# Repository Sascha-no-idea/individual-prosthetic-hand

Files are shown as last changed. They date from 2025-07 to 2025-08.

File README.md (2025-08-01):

# Open-Source Pediatric Hand Prosthesis (v4)

This repository documents the ongoing development of a lightweight, low-cost, and child-friendly 3D-printed hand prosthesis for a 9-year-old. The project started as part of a mechanical engineering course at TU Berlin and is actively being developed further.

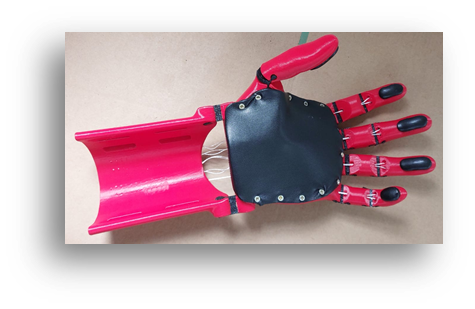
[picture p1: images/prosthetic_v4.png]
Prosthetic Hand
\
*Figure: Final design of the prosthetic hand (v4)*

---

## Project Background

The prosthesis is designed to be operated via wrist flexion and provide basic gripping functionality to support everyday activities. It is inspired by existing open-source prosthetic designs, especially from the [e-NABLE community](https://enablingthefuture.org/), and is built using accessible materials and FDM 3D printing.

---

## Project Goals

- **Individually adaptable** to user anatomy
- **Inexpensive** to produce (low-cost and standard materials)
- **Scalable and reproducible** for broader accessibility
- **Withstanding daily use**: robust, washable, skin-friendly
- **Comfortable and ergonomic**
- **Easily modifiable** and "grows" with the child
- **Printable on common FDM printers** with standard materials (PETG, TPU)

---

## Current Design Version: v4

The fourth generation (`v4`) of our design includes:

- ✅ Redesigned grip surfaces for better everyday usability
- ✅ Strong but flexible joints using TPU
- ✅ Custom string tension system (mechanical clamp)
- ✅ Modular components (easy replacement, adjustability)
- ✅ Printed using **PETG** and **TPU**, with **Dyneema®** cords

See [`/v4_final_design`](./v4_final_design/) for all STL files, assembly notes, and material details.

---

## Optimization Focus Areas

We evaluated and improved key components through iterative testing:

- `material-selection/` — optimal filament + cord materials (PETG, Dyneema)
- `finger-design/` — grip geometry & modularity
- `joint-mechanism/` — strength vs. complexity
- `band-routing/` — minimizing friction and response delay
- `tensor-system/` — new back-tensioner design
- `grip-surface/` — various high-friction materials tested
- `fit-scaling/` — adaptive sizing for different users

Detailed discussions and test results can be found under [`/optimization`](./optimization/).

---

## Repo Structure

| Folder | Description |
|---|---|
| `docs/` | Documentation and project presentation (PDF) |
| `v4_final_design/` | All current STL files and build instructions |
| `optimisation/` | Subfolders for each tested feature/improvement |
| `resources/` | Source models from e-NABLE, literature references |

---

## Credits & Acknowledgements

We gratefully acknowledge the open-source foundation by:

- [e-NABLE Kinetic Hand](https://www.thingiverse.com/thing:4618922)
- [Flexy-Hand by Gyrobot](https://www.thingiverse.com/thing:380665)

This project was developed by:
- Kristina Leberer  
- Sascha Thiede  
- Jonte Fricke  

as part of the course **"3D-Druck in der Mechanik"** at TU Berlin, supervised by **Prof. Dr. C. Völlmecke**, **Yating Ou (M.Sc.)**, and **Narges Panjalipoursangari (M.Sc.)**.

---

## Status

🟢 **v4 complete and functional**  
 - Further enhancements (grip elements, heat shrink tube, print-in-place design) in development.
- We're not in yet in contact with e-NABLE, but we plan to share our findings with them directly.

---

## Contact

For questions, feedback or collaboration proposals, feel free to open an issue or contact us directly.

---

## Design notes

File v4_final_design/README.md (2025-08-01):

# v4 Final Design – Quick Start Guide

This folder contains everything needed to replicate our current working version (v4) of the pediatric wrist-actuated prosthetic hand.

The design is based on the **Kinetic Hand by Mat Bowell**, maintained by the [e-NABLE community](https://enablingthefuture.org/). We've made minor but significant improvements to simplify usability, comfort, and assembly — particularly around the **tensioner system** and **material selection**.

---

## Required Base Files

The full set of STL files for the Kinetic Hand can be downloaded from:

🔗 [Kinetic Hand on Thingiverse](https://www.thingiverse.com/thing:4618922)

These files include all standard parts such as the palm, fingers, hinges, gauntlet, and wrist components.

We recommend downloading the latest official ZIP from Thingiverse and **replacing only the following parts with ours**.

---

## Custom Parts (included in this folder)

Located under `stl/`:

| File | Description |
|---|---|
| `tensioner_v1.stl` | Our redesigned mechanical friction-based tensioner, replacing the default flexible tensioner. Enables one-handed cable adjustment with no glue or knots. |

---

## Materials Used

| Component | Material | Note |
|---|---|---|
| Main structure | PETG | Durable and easy to print |
| Joints & pads  | TPU | Flexible (Shore A ~95) |
| Tendon cords | Dyneema® (UHMwPE) | Extremely strong, low friction |

Full material rationale in [`../optimization/`](../optimization/02_material-selection/)

> *NOTE: PETG Print Settings*  
> - Nozzle: **240–250 °C**  
> - Bed: **75–85 °C**  
> - Layer height: **0.2 mm**  
> - Walls: **3+**  
> - Infill: **25–40%** (depending on part)  
> - Cooling: **OFF or low** to prevent layer delamination  
> - Adhesion: Use brim and glue stick if needed

> *NOTE: TPU Print Settings*  
> - Nozzle: **220–230 °C**  
> - Bed: **50–60 °C**  
> - Layer height: **0.15–0.2 mm**  
> - Infill: **100% for joints**, **10–30% for grip parts**  
> - Print speed: **20–30 mm/s**  
> - Retraction: **Minimal or off**  
> - Direct drive extruder recommended

---

##  Bill of Materials (v4 Prototype)

| Part | Material | Weight | Est. Cost (PETG: 16–22 €/kg, TPU: 18–25 €/kg) |
|---|---|---|---|
| Palm | PETG | 90 g | 1.44 € – 1.98 € |
| Gauntlet | PETG | 66 g | 1.05 € – 1.45 € |
| Gauntlet Cover | PETG | 13 g | 0.20 € – 0.27 € |
| Palm Cover | TPU | 15 g | 0.27 € – 0.38 € |
| Finger Plate | PETG | 52 g | 0.83 € – 1.14 € |
| Hinge Plate | TPU | 17 g | 0.31 € – 0.43 € |
| Grip Plate | TPU | 7 g | 0.13 € – 0.18 € |
| **TOTAL (Printed)**| – | **260 g** | **4.23 € – 5.38 €** |

> *Dyneema cord (0.4 mm): ~0.12 €/m used (~1.00 € total)*  
> *Fasteners: ~1.00–2.00 € depending on source*

**Total material cost: under 10 €**

## Tensioning System

Replace the default Kinetic Hand tensioners with our friction-clamp version. Instructions:

1. Route tendon cord through the channel
2. Loop cord around central screw hole
3. Tighten screw to secure cord in place
4. To adjust tension: slightly loosen and reposition

See details in [`../optimisation/`](../optimization/04_tensor-system/)

---

## Optional Add-Ons

- [`../optimisation/05_grip-surface/`](../optimisation/05_grip-surface/) – Test results and methods for grip materials  
- [`../optimisation/06_fit-scaling/`](../optimisation/06_fit-scaling/) – Notes on fit strategy and scaling method

---

## Licensing Notice

This version is a derivative work of:

- **Kinetic Hand by Mat Bowell**  
  [Thingiverse Link](https://www.thingiverse.com/thing:4618922)  
  Licensed under [CC BY-NC-SA 4.0](https://creativecommons.org/licenses/by-nc-sa/4.0/)

Our modifications and additions are released under the same license.  
See [`LICENSE`](../LICENSE) in the main repository root.

---

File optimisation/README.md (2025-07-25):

# Optimisation
This directory contains the optimisation process for the individual prosthetic hand project. We put a lot of effort into improving the design, materials, and functionality of the prosthesis and split the optimisation process into several subfolders, each focusing on a specific aspect of the prosthesis.

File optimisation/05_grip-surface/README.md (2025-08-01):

# Grip Surface Optimisation

This section documents our experiments with grip surface solutions to enhance the functionality of the prosthetic hand. Grip performance is critical for tasks like holding bottles, pens, or toys — especially for a child user.

While the Flexy-Hand used **smooth contact areas**, the default model for the Kinetic Hand has recommends two-component silicone or flexible filament inserts, these solutions come with significant drawbacks. We explored several alternatives — including a **custom hot glue in-place injection moulding** process developed during the project.

---

## Official Recommendations

The Kinetic Hand assembly guide suggests two main grip-enhancing approaches:

### 🔸 Silicone Inserts (Two-Part Silicone)

- **Method**: 3D print moulds and cast custom inserts
- **Material**: Skin-safe silicone, Shore A 25–45
- **Estimated Cost**: ~27 € for 500 g (no smaller sets available)
- **Pros**: High grip, skin-safe, durable
- **Cons**: Expensive, high effort, wasteful for small production

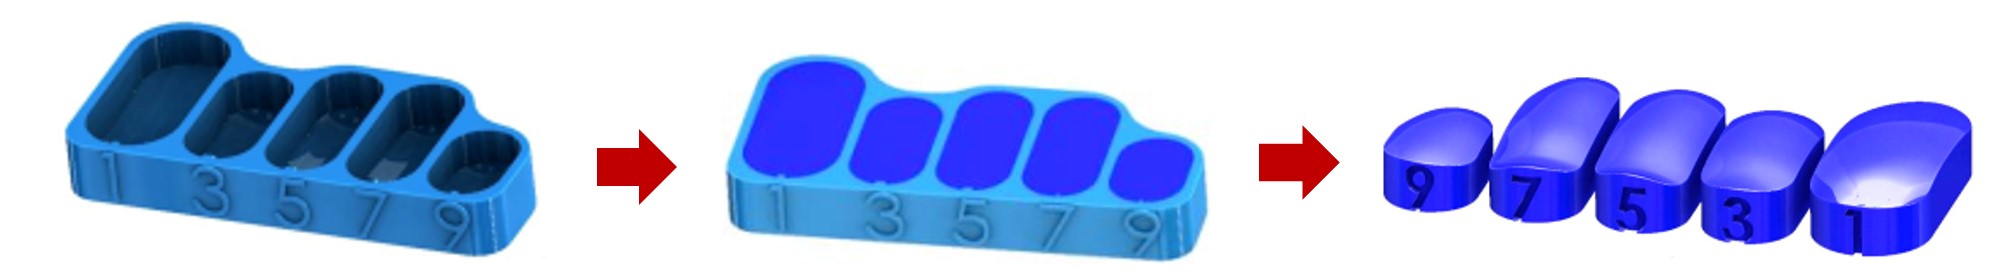
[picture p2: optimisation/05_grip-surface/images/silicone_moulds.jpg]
Silicone Insert Mould

*Figure: Printed silicone moulds for two part silicone (Image Source: Kinetic Hand Assembly Manual, Rev. 9/10/2020).*

---

### 🔸 Printed Grip with Ninjaflex

- **Method**: Print grip pads directly in ultra-flexible filament
- **Material**: Ninjaflex (Shore A ~85)
- **Estimated Cost**: ~30 € per 250 g spool
- **Pros**: Fully integrated into the model, good grip
- **Cons**: Very hard to print, not standard on most printers

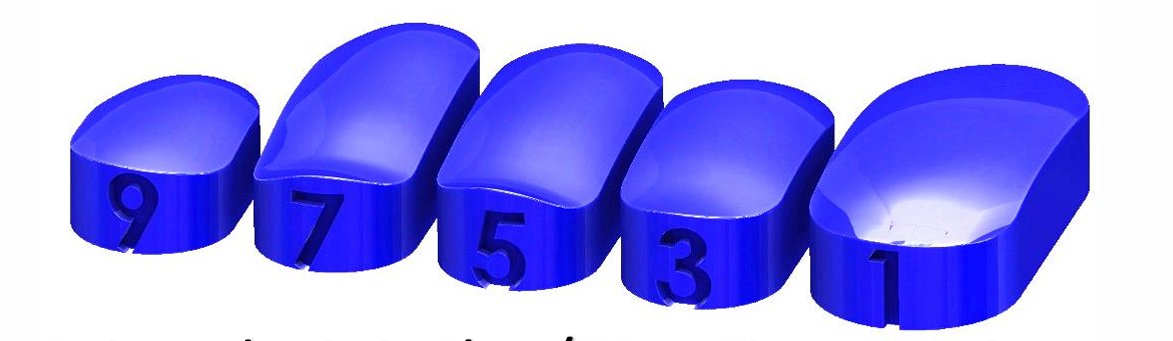
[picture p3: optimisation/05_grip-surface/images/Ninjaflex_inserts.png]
Ninjaflex Grip Example

*Figure: Example of Ninjaflex grip pads (Image Source: Kinetic Hand Assembly Manual, Rev. 9/10/2020).*

---

## Our Experiments & Alternatives

We tested several cost-effective and accessible alternatives, aiming for low manual effort, minimal cost, and wide availability.

---

### 🟠 1. Textured TPU Surface

- **Method**: Printed a grip surface with modeled texture using more affordable stanard TPU (Shore A ~90)
- **Pros**: Fully printable, no extra steps
- **Cons**: Too slippery; texture ineffective at this scale (on FDM printers)

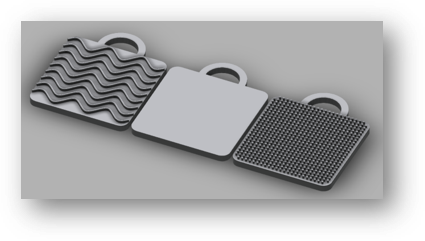
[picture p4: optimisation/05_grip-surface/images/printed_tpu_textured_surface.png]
Textured TPU Example


---

### 🟠 2. Full-Hand Latex Glove

- **Method**: Stretch a latex glove over the entire hand
- **Pros**: Good grip, instant coverage
- **Cons**: Not breathable → makes skin sweaty; less durable

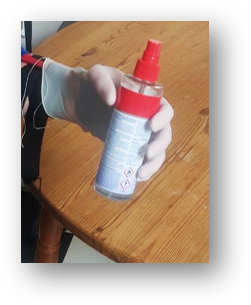
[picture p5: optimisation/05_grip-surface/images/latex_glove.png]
Latex Glove Example


---

### 🟢 3. Thick Latex Pads (Upcycled Material)

- **Method**: Cut grip pads from old latex leggings and glue them onto fingers and screw them onto the palm
- **Pros**: Very effective grip; comfortable; cost-efficient if sourced
- **Cons**: Manual cutting/gluing effort; sourcing may be inconsistent

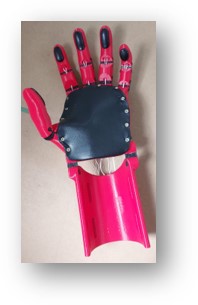
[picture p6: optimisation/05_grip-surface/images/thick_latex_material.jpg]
Latex Pad Example


💡 *This is the current solution used in our v4 prototype.*

---

### ✅ 4. Hot Glue In-Place Injection Moulding *(Experimental – v5 Candidate)*

- **Method**:  
  1. Design fingers with small recessed cavities  
  2. 3D-print a snap-on **injection mould** with a hole and fuzzy skin texture  
  3. Coat mould interior with **sugar water** as a release agent and let it dry  
  4. Snap mould onto finger  
  5. Inject **hot glue (130 °C)** into mould  
  6. Let it cool, remove mould, and rinse off sugar layer

- **Material**: Standard hot glue sticks (~Shore A 80)
- **Pros**:  
  - Extremely grippy  
  - Fast and low-cost  
  - No adhesives needed  
  - Permanent bond to the finger  
  - Moulds are reusable  
- **Cons**:  
  - Requires some heat control  
  - Not yet tested on full hand

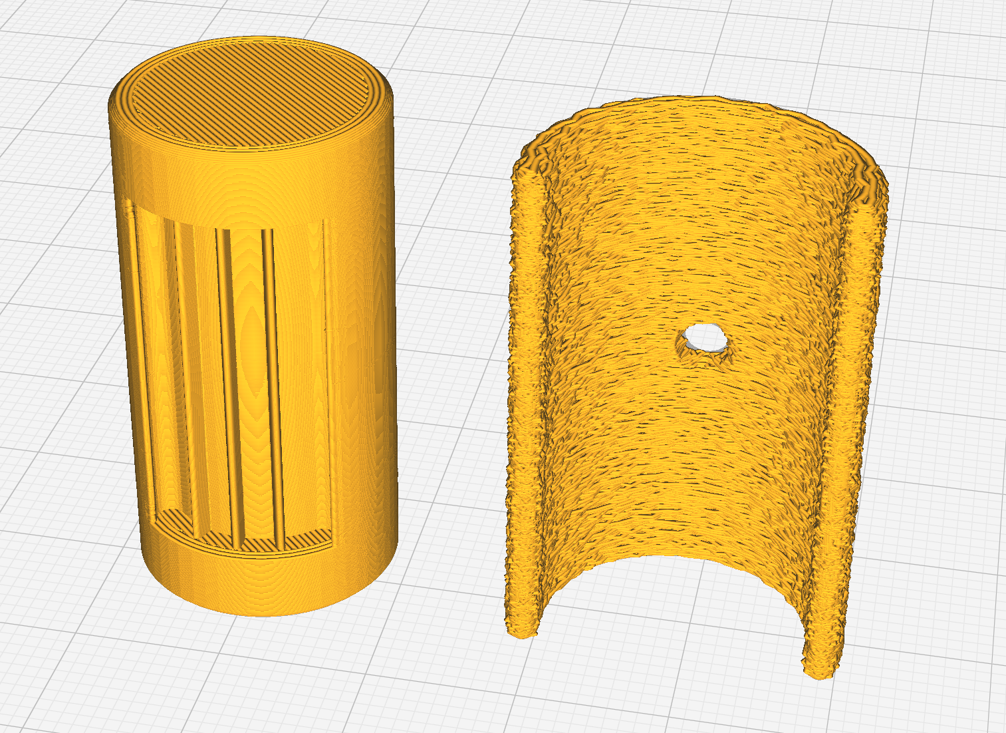
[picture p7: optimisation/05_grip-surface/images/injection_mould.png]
Test finger and snap-on mould
\
*Figure: Test finger with snap-on injection mould with fuzzy skin.*\
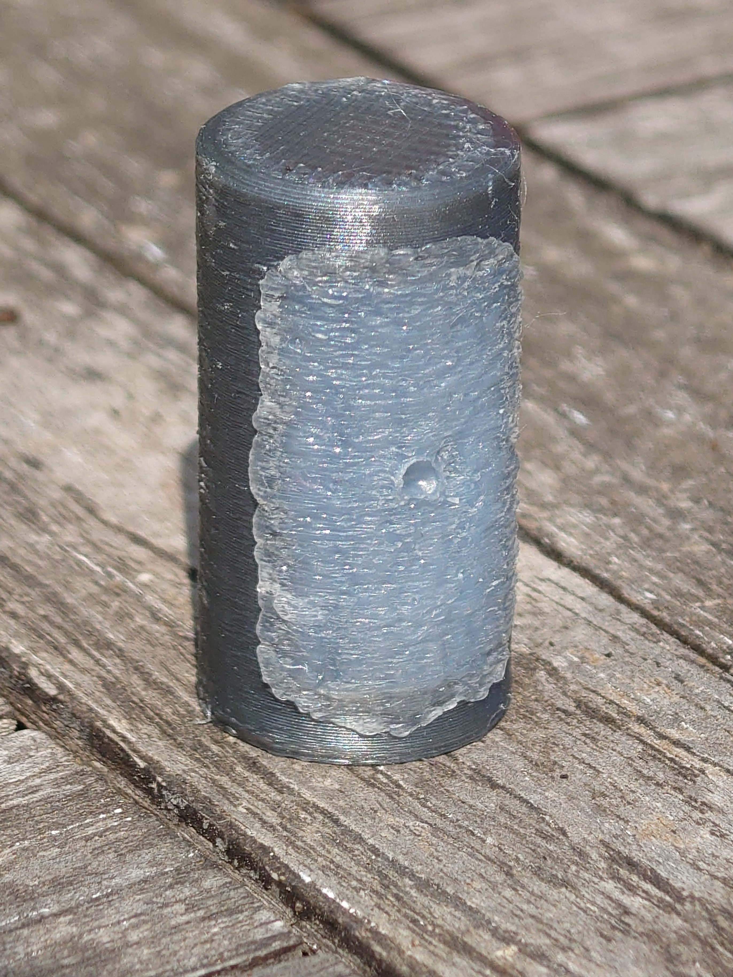
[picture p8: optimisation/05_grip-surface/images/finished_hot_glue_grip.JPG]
Finished hot glue grip
\
*Figure: Finished hot glue grip after injection and cooling.*

This technique will likely be included in our next version (v5).

---

## Summary of Tested Grip Solutions

| Method | Grip Quality | Cost  | Reusability | Required Tools | Status |
|---|---|---|---|---|---|
| Silicone inserts | ✅ High | 🔴 High | ✅ High | Casting tools, silicone| Not used |
| Ninjaflex print | ✅ High | 🔴 High | ✅ High | Soft-TPU-capable printer | Not used |
| Textured TPU | 🔴 Low | 🟢 Low | ✅ High | Basic FDM printer | Rejected |
| Latex glove | 🟢 Moderate | 🟢 Low | 🔴 Low | None | Rejected |
| Latex pads (upcycled) | ✅ High | 🟢 Low | 🟡 Medium | Scissors, glue | ✅ Used (v4)  |
| Hot glue injection mould  | ✅ High | 🟢 Low | ✅ High | Hot glue gun, mould | 🔜 v5 planned |

---

## Files & Resources

- `stl/grip_test_finger_with_cavity.stl` – Test finger with moulded grip cavity  
- `stl/hotglue_snap_mould.stl` – Snap-on grip mould 

---

## Learnings & Next Steps

- **Grip surface = critical** to daily usability, especially for small objects
- The **hot glue technique** is our most promising low-cost approach
- thick **latex material** already works well

---

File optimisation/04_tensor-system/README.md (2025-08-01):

# Tensor System

This section documents the design and motivation behind our custom **string tensioner system**. The tensioners are a crucial part of the prosthesis: they enable adjustment of the tendon cords that actuate the fingers via wrist movement.

---

## Standard Tensioner (Kinetic Hand Design)

The official Kinetic Hand assembly manual describes a multi-step process for installing and calibrating the tendon cords using **flexible tensioners**:

1. Screw the flexible tensioners into the gauntlet at one of several predefined positions.
2. Tie the tendon cord around the tensioner, initially with **temporary slip knots**.
3. Manually test the finger closure (adjusting for timing and symmetry).
4. Tie **permanent knots** (surgeon’s knot), apply **super glue**, and trim.
5. Optionally reposition the tensioners for final calibration.

**Drawbacks:**
- Requires **both hands** to tie knots and make adjustments.
- Tuning process is **time-consuming and difficult to repeat**.
- Knots and glue introduce **irreversible steps**.
- wear on screw holes with repeated adjustments.

*See the official assembly instructions (Step 12–21) for full procedure.*

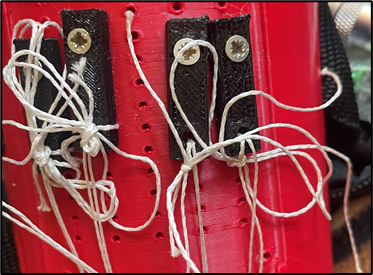
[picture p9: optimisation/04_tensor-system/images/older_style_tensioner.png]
Standard Tensioner


*Figure: Standard tensioner system from Kinetic Hand assembly manual, but with bow instead of surgeon’s knot during prototyping.*

---

## Our Custom Tensioner Design

To make the system more **user-friendly, reliable, and adjustable**, we designed a **two-part mechanical clamp** that holds the tendon in place by friction.

### Key Features:
- No knots or glue required
- Fully **adjustable with one hand**
- Uses only **a single M2 screw**
- Cords can be inserted, tightened, and re-tensioned **without tools**
- Reversible and reusable (decreases wear on screw holes)

### How It Works:

The custom tensioner consists of:
- A **base part** with a guide channel
- A **cap part** that clamps the tendon in place
- One **M2 screw** that connects both parts and compresses the cord

The cord is routed around the screw shaft and sandwiched between the two halves. As the screw is tightened, friction secures the cord firmly in position. To adjust, the screw is loosened slightly, the cord is pulled or released, and the screw is re-tightened.

<div style="display: flex;">
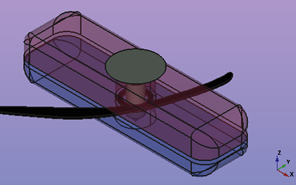
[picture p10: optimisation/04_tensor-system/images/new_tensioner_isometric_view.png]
New Tensioner CAD
  
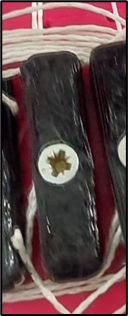
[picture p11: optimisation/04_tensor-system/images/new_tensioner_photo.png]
New Tensioner Assembly
  
</div>

*Figure 1: Isometric view of the new custom tensioner design.*\
*Figure 2: Image of the assembled new custom tensioner design.*

---

## Assembly Instructions

1. Insert the tendon cord into the guide path in the **base part**.
2. Loop the cord around the central screw hole.
3. Place the **cap part** on top.
4. Insert and tighten the **M2 screw** gently until resistance is felt.
5. Test the finger actuation.
6. Adjust by loosening and repositioning the cord as needed.

---

## Advantages at a Glance

| Feature | Standard System | Custom Tensioner |
|---|---|---|
| Tool-free adjustment | ❌ No | ✅ Yes |
| Requires knot tying | ✅ Yes | ❌ No |
| Requires glue | ✅ Yes | ❌ No |
| One-handed operation | ❌ No | ✅ Yes |
| Reusability | ❌ Limited | ✅ High |

---

## Files & Resources

- [`tensioner_custom_v1.stl`](../../v4_final_design/stl/Tensor_new.stl)

---

## Future Improvements

- Incorporate quick-release or snap-fit features for even faster cord swaps
- or increase longevity of screw holes, consider using a **threaded insert** instead of direct threads in the plastic

---

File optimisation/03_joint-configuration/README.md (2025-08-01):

# Joint Configuration

This section documents our evaluation of joint types used in the prosthetic fingers and palm. Finger joint design is critical to achieving a balance between stability, flexibility, durability, and ease of assembly.

We compared three joint types:

- **Flexible printed hinges (default TPU design)**  
- **Flexible joints with shrink tubing**  
- **Standard mechanical (pinned) joints**

---

## Overview of Joint Types

Joint Types Comparison
*Figure: Extract from project presentation slide (July 2025)*

---

## Why We Didn't Use Shrink Tubing (Yet)

Although the shrink-tube joint is promising — especially due to the clean look and quick assembly — we encountered **several material challenges**:

- Most common shrink tubing (polyolefin) is too **stiff** in larger diameters
- Wall thickness becomes problematic for our small-scale parts
- We ordered alternative materials: **braided PET tubing** and **thin silicone tubing**, but delivery was pending at the time of the current version (`v4`)
- Further material testing is planned — this joint type may still become a viable option for future versions

**Update (2025-07-31): Our Shrinking Tube order arrived**\
We tested:
- **Braided PET tubing**: Works in general, but sto stiff, not enough grip and not waterproof
- **PVC grip tubing (for fishing rod handles)**: Works exceptionally well, nice and thin, flexible, much better grip than polyelofin tubing, but PVC might contain harmful chemicals.
- **Silicone tubing (non-shrink, food grade)**: Works well, fit is a bit loose, because it does not shrink, we were not able to source larger diameters than ID 12 mm, OD 14 mm yet without thicker walls.

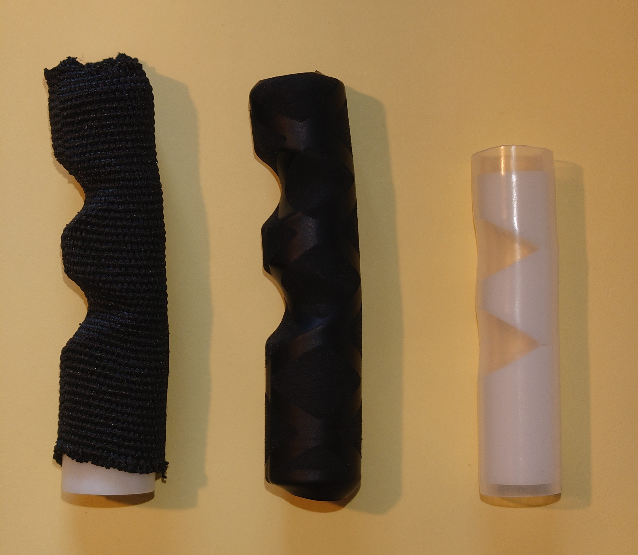
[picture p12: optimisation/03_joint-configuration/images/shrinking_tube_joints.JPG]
Shrink Tube Joint

*Figure: Print-in-place shrink tube joint test finger with braided PET tubing (left), PVC grip tubing (middle), and silicone tubing (right).*

Our current tests of this new joint type are very promising. Especially the PVC grip tubing works very well and provides reliable re-opening of the finger, but we are still concerned about the chemicals in PVC. The silicone tubing is a good alternative, although a bit stiff, and we need to find a source for larger diameters with thin walls. Furthermore, we need to test the long-term wear resistance, as non of these tubings are designed for repeated bending. Once these tests are complete, we can work on a print-in-place finger design that uses the shrink tube joint.

Shrink Tube Joint Bending Test
*Figure: Bending test of PVC grip tubing joint. The joint opens reliably, but we need to test long-term wear resistance.*

---

## Current Decision

For our current build (v4), we are using the **default flexible TPU joints** provided in the Kinetic Hand design. We optimized the **print settings** for these joints (infill, wall count, material choice) to ensure:

- Smooth opening motion after gripping
- Adequate flexibility for kid’s strength
- Durability over extended use

---

## Print Settings for TPU Joints

| Parameter | Value / Recommendation |
|---|---|
| Layer height | 0.2 |
| Wall/perimeter | 3 |
| Infill | 30 % |
| Print speed | 30 mm/s |
| Material used | TPU (Shore A 90) |

Please note that the actual print settings vary and depend on your specific TPU brand and printer configuration. The goal is to tune the strength of the joints so that the hand will reopen completely with no unnecessary increase in required closing force.

---

## Next Steps

We plan to revisit the shrink tube approach, given that our new material has arrived. Our goal is to evaluate:

- Long-term wear resistance
- Assembly effort
- Performance under repetitive motion

Furthermore, we will run more tests with **PCTG** as a potential joint material, which would enable us to print the entire hand in one piece, eliminating the need for joints altogether.

---

## References

- [Kinetic Hand on Thingiverse](https://www.thingiverse.com/thing:4618922) — original joint design
- Internal presentation slide (July 2025): *Comparison of joint types*

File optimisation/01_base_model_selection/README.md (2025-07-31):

# Base Model Selection

In this section we explain our selection process of an existing prosthetic as our base model for further development. In our initial research we found several open-source designs that could be used as a starting point. With our criteria in mind — especially the preference for flexible joints over mechanical pivot joints for simplicity and printability — we narrowed it down to two well-known models:

- [**Flexy-Hand 2** by Gyrobot](https://www.thingiverse.com/thing:380665)  
- [**Kinetic Hand** by Mat Bowell](https://www.thingiverse.com/thing:4618922)

Both are distributed and maintained by the [e-NABLE community](https://enablingthefuture.org/) and come with open-source licenses, making them suitable for educational and humanitarian use.

---

## Evaluation Criteria

We compared the models based on the following criteria:

- Simplicity of assembly  
- Modularity and adjustability  
- Suitability for children (size, safety, usability)  
- Maintenance and repairability  
- Printability on standard FDM printers  
- Availability of documentation and community support

---

## Comparison Table

| Feature | Flexy-Hand 2 by Gyrobot | Kinetic Hand by Mat Bowell |
|---|---|---|
| **Joint type** | Flexible (printed hinges) | Flexible (printed hinges) |
| **Finger grip surface** | Smooth (no texture) | Includes optional silicone inserts |
| **Seilzüge (tendon routing)**  | Open, exposed routing | Covered routing with palm cover |
| **Assembly complexity** | Very low | Moderate (more parts, hinges are hard to assemble) |
| **Fit customization** | Simple scaling | Advanced: Hand-o-matic | |
| **Documentation quality** | Limited | Very good (Thingiverse + PDF manuals) |
| **Visual appeal** | Basic | More anatomical & refined |
| **Tensor adjustability** | Linear screw tensors | Fixed TPU tensioners (limited adjustability) |
| **License & community support**| CC BY-NC-SA 4.0 | CC BY-NC-SA 4.0 |

---

## Decision & Rationale

We chose the **Kinetic Hand** by Mat Bowell as the foundation for our development due to the following advantages:

- Better grip design with modular surfaces
- enclosed tendon routing
- Visually more appealing and ergonomic
- Excellent documentation and broader community adoption

While it has more parts and requires more effort during assembly, its **long-term modularity and flexibility** made it a better foundation for an individually optimized prosthesis.

---

## Credits

- **Flexy-Hand 2** by Steve Wood / Gyrobot  
  - [Thingiverse page](https://www.thingiverse.com/thing:380665)  
  - [Gyrobot website](https://www.gyrobot.co.uk)

- **Kinetic Hand** by Mat Bowell  
  - [Thingiverse page](https://www.thingiverse.com/thing:4618922)  
  - [Free 3D Hands website](https://free3dhands.org/)
- **e-NABLE Community**  
  - [Enabling the Future](https://enablingthefuture.org/)

All designs used under open-source licenses. We are grateful to the creators and the e-NABLE community for their dedication to accessible prosthetics.

---

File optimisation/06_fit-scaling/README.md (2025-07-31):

# Fit & Scaling

This section documents our approach to adapting the prosthetic geometry to fit the user's hand, with a focus on **scaling strategy**, **comfort**, and **fit stability**. Ensuring a precise and ergonomic fit is essential for usability — especially for a growing child.

---

## Initial Idea: Non-Proportional Scaling

In our early experiments, we attempted **axis-specific (non-uniform) scaling** to better match the forearm's anatomical proportions. However, this led to multiple problems:

- 🚫 **Tendon channels collapsed** and became non-functional
- 🚫 **Joint geometry distorted**, leading to mechanical issues
- 🚫 **Finger proportions became unnatural and visually awkward**

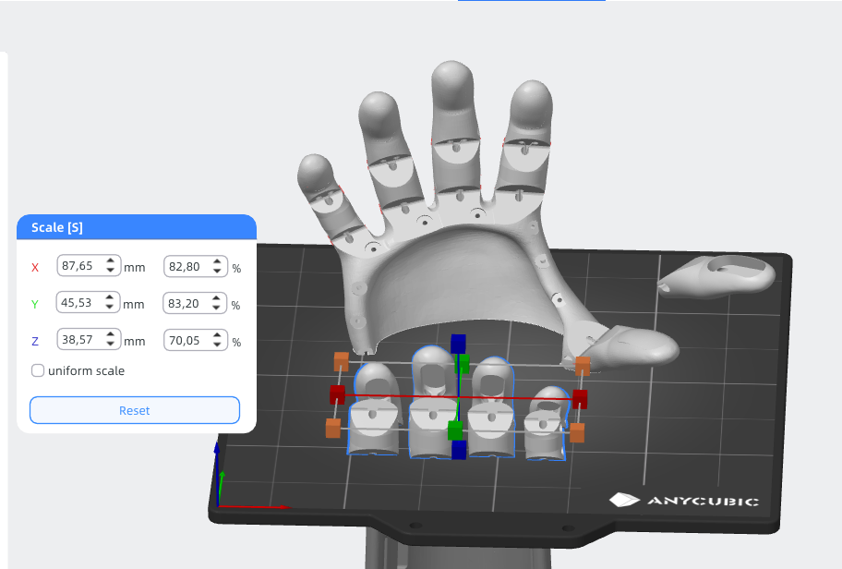
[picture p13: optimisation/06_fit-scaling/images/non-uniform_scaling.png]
Deformed Geometry Example

*Figure: Deformed geometry due to non-uniform scaling*

---

## Final Decision: Proportional Scaling

After encountering the issues with axis scaling, we returned to a simpler and more robust solution: **uniform (proportional) scaling** of the entire model.

- Required **no modifications** to the geometry
- Maintained **functional integrity** of the joints and tendon paths
- Produced a result that **fit our 9-year-old user** well

💡 *We did not need to rely on the sizing tables provided in the official documentation, because sizing was easy in our specfic case.*

---

## Fit Insert: Not Required in Our Case

The Kinetic Hand documentation describes optional **TPU fit inserts** to stabilize the wrist position and prevent the forearm from slipping inside the palm socket.

> *"The Insert is designed to be a soft cushion inside the Kinetic Hand. It stops the partial hand from sliding forward and keeps the wrist at the hinge position. It is shaped as a precise fit into the cavity of the Palm."*  
— *Kinetic Hand Assembly Manual, Step 26*

### Why We Didn't Use It

- Our proportional scaling resulted in a **snug, stable fit** for the user
- No noticeable sliding or discomfort was observed
- The wrist hinge aligned well with the user's joint without additional padding

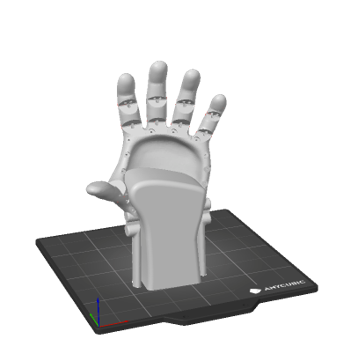
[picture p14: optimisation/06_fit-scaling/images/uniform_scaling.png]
Uniform Scaling Result


---

## Alternative Insert Options (Hypothetical)

If an insert had been required, we considered two affordable and low-tech alternatives:

### 1. Kitchen Silicone + Starch Putty (Untested)

- **Method**: Mix **hardware store silicone** with **cornstarch** to form a moldable, skin-safe padding that hardens over time
- **Pros**: Inexpensive, conformal, moldable by hand
- **Cons**: Requires drying time, emits acetic acid while curing

### 2. Foamed TPU (e.g. LW-TPU, Untested)

- **Method**: Print the insert using lightweight or foaming TPU to reduce weight and improve cushioning
- **Pros**: Lightweight, springy, printable
- **Cons**: Expensive, hard to source, needs tuned settings

> *Note: Neither approach was implemented in v4, but both remain valid ideas for future versions or other users with different anatomical requirements.*

---

## Summary

| Approach | Tested? | Result |
|---|---|---|
| Non-proportional scaling | ✅ Yes  | ❌ Rejected due to geometry and function issues |
| Proportional scaling | ✅ Yes  | ✅ Used in v4, provided excellent fit |
| TPU insert (standard) | ❌ No | Not needed |
| Silicone putty insert | ❌ No | Viable fallback (hypothetical) |
| Foamed TPU insert | ❌ No | Experimental idea for future |

---

## References

- *Kinetic Hand Assembly Manual*, e-NABLE (Step 26)  
- Internal presentation slides – Fit Scaling,  July 2025 
- Informal guides for DIY silicone putty (silicone + starch)

---

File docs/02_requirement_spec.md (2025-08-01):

# Requirement Specification – Pediatric Wrist-Actuated Hand Prosthesis

## 1. Project Purpose

The goal of this project is to develop a 3D-printable, wrist-actuated hand prosthesis for a 9-year-old user. The device should be low-cost, ergonomic, and enable the user to grasp everyday objects independently.

## 2. Functional Requirements

| ID | Requirement | Description |
|---|---|---|
| FR01 | Wrist-actuated finger motion | The prosthesis must enable grip via wrist flexion. |
| FR02 | Passive return to open state | Fingers must return to the default open state when wrist is relaxed. |
| FR03 | Object grasping | Must securely grasp objects such as a cup, pencil, or toy. |
| FR04 | Replaceable string system | Cables/strings should be replaceable and easy to calibrate. |

## 3. Non-Functional Requirements

| ID | Requirement | Description |
|---|---|---|
| NFR01 | Comfortable fit | Should not cause pain or discomfort during wear. |
| NFR02 | Durable materials | Components must withstand regular use by a child. |
| NFR03 | Lightweight | The prosthesis should not exceed 200 grams. |
| NFR04 | Hygienic and skin-safe materials | Materials must be biocompatible and easy to clean. |
| NFR05 | Cost-effective | Total material cost should remain under €10. |
| NFR06 | Openly reproducible | Design should use standard FDM materials and printers. |
| NFR07 | Modular design | Should allow partial replacements and scaling. |

## 4. Design Constraints

- Printable using FDM printers with nozzle ≥ 0.4 mm.
- No support structures required (where avoidable).
- Designed for printing with widely available and easy-to-print materials, like PETG and TPU.
- Cord system must avoid elastic materials like nylon.
- Maximum build plate size: 220 × 220 mm.

## 5. Intended Use & Limitations

- Designed for passive prosthetic use (no active sensors yet).
- Grip force depends on wrist motion and cord stiffness.
- Not intended for heavy load-bearing use or high-impact sports.

## 6. Stakeholders

- **End user**: 9-year-old child with partial forearm.
- **Family**: supports daily use and maintenance.
- **University Team**: responsible for design, testing, and documentation.
- **Open-source Community**: potential contributors and replicators.

---

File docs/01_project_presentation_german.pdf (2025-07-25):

Fakultät für Verkehrs- und Maschinensysteme
Institut für Mechanik

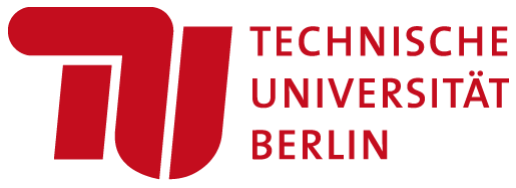
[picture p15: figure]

Fachgebiet Stabilität und Versagen funktionsoptimierter Strukturen Prof. Dr. C. Völlmecke

Gruppe C
Kristina S. Leberer
Sascha G. Thiede
Jonte C. Fricke

Projekt: 3D Druck in der Mechanik

# Die Handprothese

Seite 2 | Gruppe C | 3D-Druck in der Mechanik | Die Handprothese | 15. Juli 2025

# Agenda

- Motivation
- Projektziel und Problemkontext
- Projekte & Open-Source Community
- Vorgehen
- Meilensteine
- Iterative Herangehensweise
- Optimierungsziele
- Ergebnisse
- Optimierungen
- Kosten & Material
- Fazit
- Projektgestaltung und Umsetzung
- Bewertung der entstandenen Prothese
- Geplante Weiterentwicklungen und Unterstützung

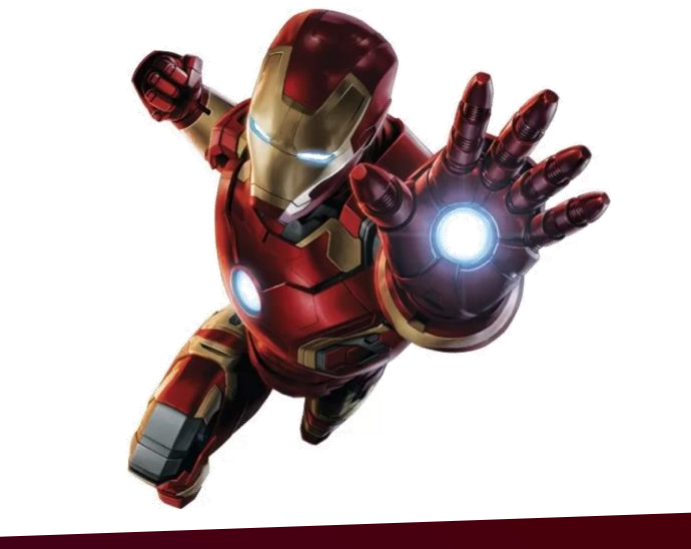
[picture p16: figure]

# Motivation

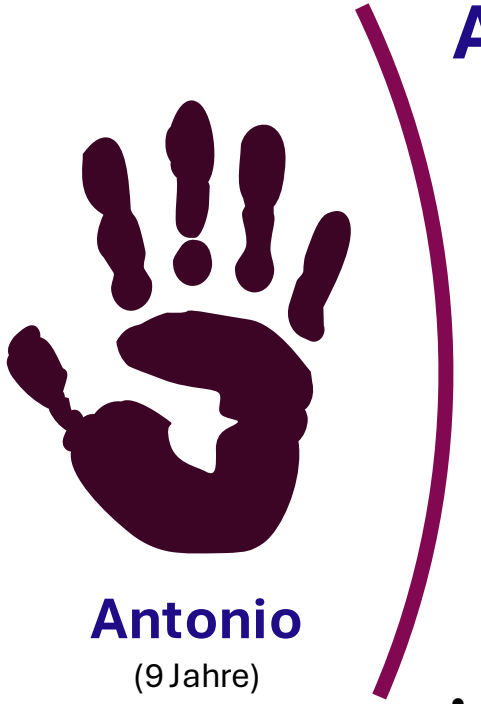
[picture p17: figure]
Antonio; (9 Jahre)

Seite 4 | Gruppe C | 3D-Druck in der Mechanik | Die Handprothese | 15. Juli 2025

# Projektziel

## Erstellung und individuellen Handprothese

# Anforderungen

### - individuell anpassbar

### - robust, funktional, zuverlässig

### - bequem & optisch ansprechend

### - kostengünstig herzustellen

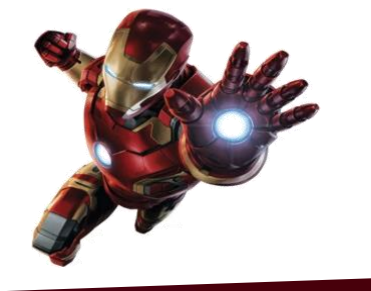
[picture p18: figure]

### - hygienisch & biokompatibel

### - einfach herzustellen

### - mitwachsend

Flexy-Hand by Gyrobot

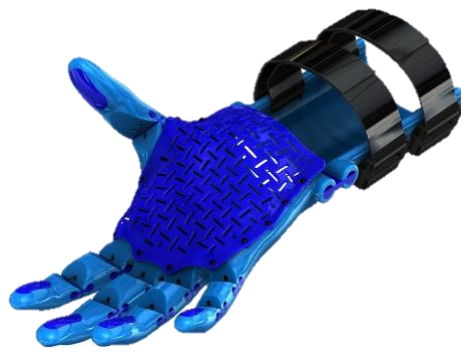
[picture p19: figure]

e-NABLE Kinetic Hand

https://www.thingiverse.com/thing:380665

https://www.thingiverse.com/thing:4618922

# e-NABLE (open-source Community)

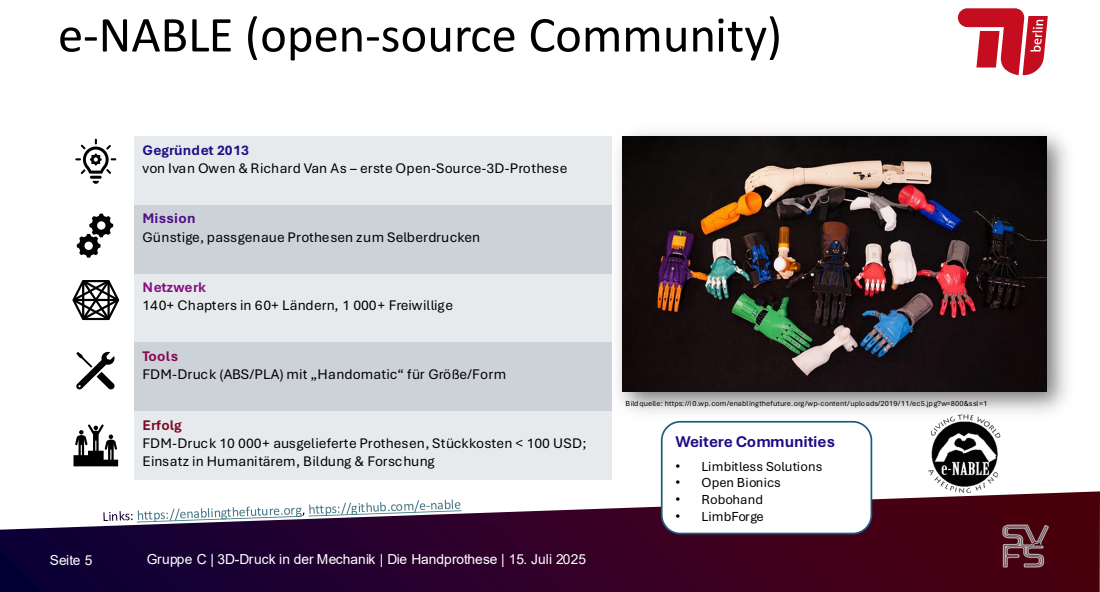
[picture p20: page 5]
Seite 5; Gruppe C | 3D-Druck in der Mechanik | Die Handprothese | 15. Juli 2025

Gegründet 2013
von Ivan Owen & Richard Van As – erste Open-Source-3D-Prothese

Mission
Günstige, passgenaue Prothesen zum Selberdrucken

Netzwerk
140+ Chapters in 60+ Ländern, 1 000+ Freiwillige

Tools
FDM-Druck (ABS/PLA) mit „Handomatic“ für Größe/Form

Bild quelle: https://i0.wp.com/enablingthefuture.org/wp-content/ uplo ads/2019/ 11/ec5.jp g?w=800&ssl=1
Weitere Communities
• Limbitless Solutions
• Open Bionics
• Robohand
• LimbForge

Erfolg
FDM-Druck 10 000+ ausgelieferte Prothesen, Stückkosten < 100 USD;
Einsatz in Humanitärem, Bildung & Forschung

# Vorgehen

Seite 7 | Gruppe C | 3D-Druck in der Mechanik | Die Handprothese | 15. Juli 2025

# Meilensteine

- Recherche
- Modellauswahl
- Maßaufnahme
- Problemanalyse
Recherche | Prototypenerstellung | Optimierung | Abschluss
| ▪ ausgewählte Modelle drucken ▪ Verarbeitungsverfahren testen ▪ Maßanpassung ▪ vertiefte Materialauswahl | ▪ Analyse der Haftreibung ▪ Griffstärke und -geometrie optimieren | ▪ Modell finalisieren ▪ Dokumentation ▪ Übergabe & Schulung

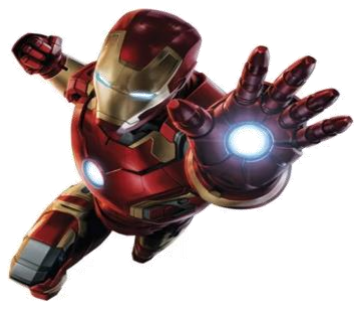
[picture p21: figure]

# Methodische Herangehensweise (iterativ)

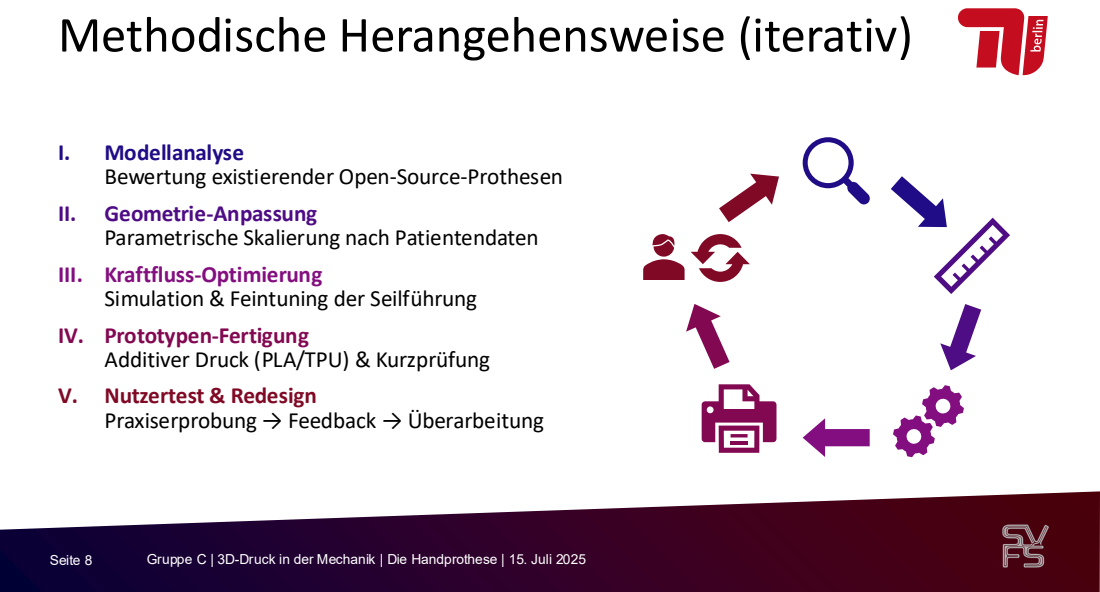
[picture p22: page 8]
Seite 8; Gruppe C | 3D-Druck in der Mechanik | Die Handprothese | 15. Juli 2025; Geometrie-Anpassung

I. Modellanalyse
Bewertung existierender Open-Source-Prothesen
Parametrische Skalierung nach Patientendaten
III. Kraftfluss-Optimierung
Simulation & Feintuning der Seilführung
IV. Prototypen-Fertigung
Additiver Druck (PLA/TPU) & Kurzprüfung
V. Nutzertest & Redesign
Praxiserprobung → Feedback → Überarbeitung

Seite 9 | Gruppe C | 3D-Druck in der Mechanik | Die Handprothese | 15. Juli 2025

# Optimierungsziele

Ergonomie Verbesserung von Tragekomfort und individueller Passform Funktionalität Sicheres Greifen alltäglicher Gegenstände mit möglichst wenig Kraftaufwand Materialwahl Leicht, robust, kostengünstig und für den Nachdruck geeignet Befestigungsmechanismus Stabiler Halt bei gleichzeitig einfacher Handhabung

### Anpassbarkeit & Modularität Möglichkeit zur schnellen Justierung und Erweiterung der Prothese

# Ergebnisse

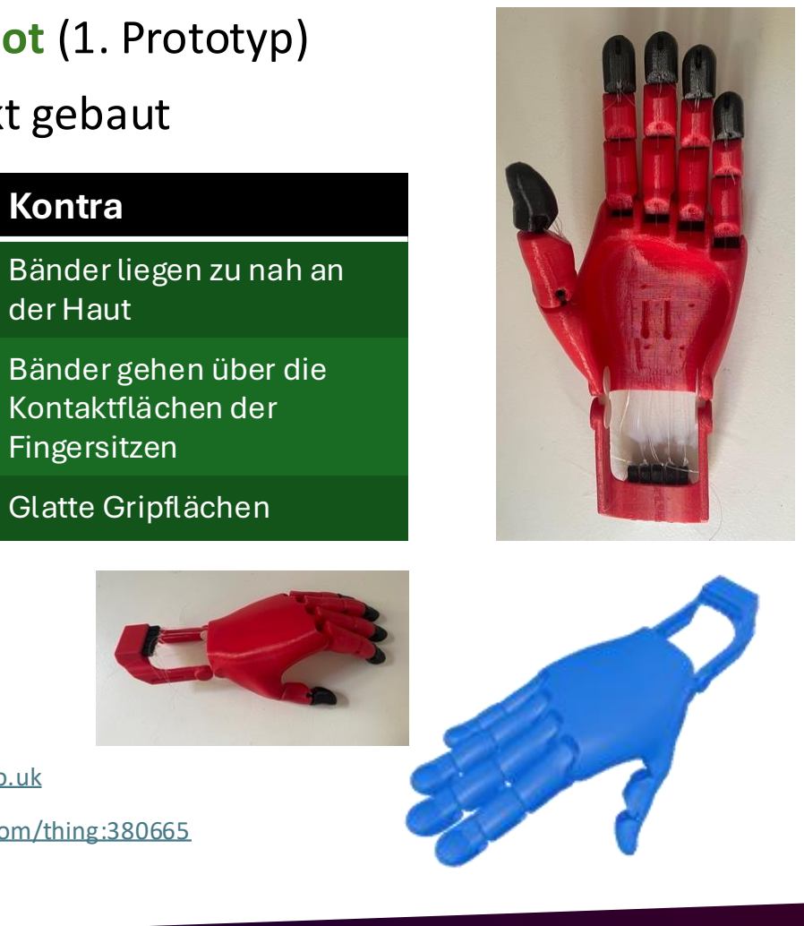
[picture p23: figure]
Bänder gehen über die Kontaktflächen der Fingersitzen; Glatte Gripflächen

Seite 11 | Gruppe C | 3D-Druck in der Mechanik | Die Handprothese | 15. Juli 2025

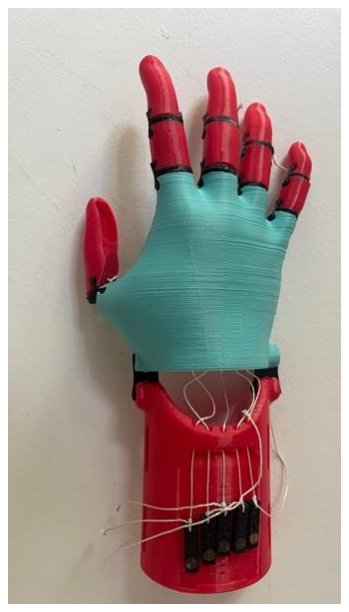
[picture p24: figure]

Model von e-NABLE (finales Model)
- im Projekt gebaut und optimiert

HOME: https://enablingthefuture.org

STL: https://www.thingiverse.com/thing:4618922

# Zwei Modelle

Model von Gyrobot (1. Prototyp)
- vor dem Projekt gebaut

HOME: https://www.gyrobot.co.uk

STL: https://www.thingiverse.com/thing:380665

Pro | Kontra
weniger Teile | Bänder liegen zu nah an
der Haut
Tensoren der Bänder
simple
Pro | Kontra
Form der
Handaussparung

mehr Teile

optisch ansprechender Tensoren nicht justierbar
bessere Anleitung | schwieriger beim Zusammenbauen der Gelenke

fortschrittlicher

Seite 12 | Gruppe C | 3D-Druck in der Mechanik | Die Handprothese | 15. Juli 2025

# Überblick: Optimierungsansätze

### - Materialwahl

Hand, Bänder

### - Herstellung

vereinfachte Verarbeitungsprozesse

### - Grip-Flächen

Material- und Oberflächenalternativen

### - Gelenke

TPU-Gelenke durch Schrumpfschlauch ersetzten

### - Tensoren

Bänderbefestigung mit einfacher Kalibrierungsmöglichkeit der Spannkraft

### - Bänder

Kraftverteilungsalternative

### - Innere Flächen

Bequemlichkeitsanpassung durch Handschuh

Bänder | Tensoren

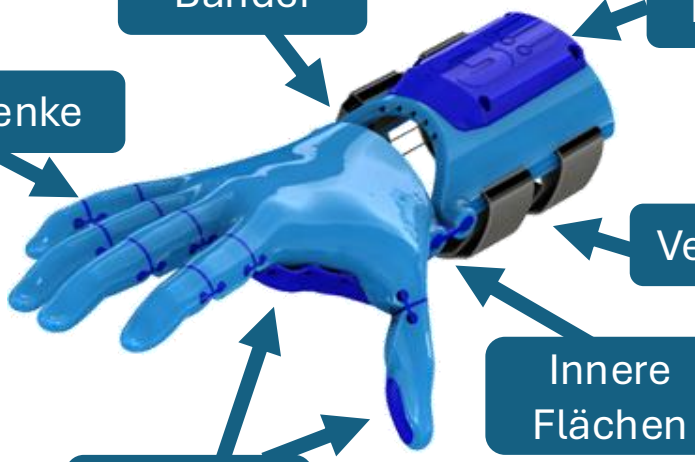
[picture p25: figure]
Innere Flächen

### Grip-Flächen

### Gelenke

### Verschluss

# Material Hand

PC-ABS | ABS | Nylon | PCTG | PLA/PLA

Seite 13; Gruppe C | 3D-Druck in der Mechanik | Die Handprothese | 15. Juli 2025; Robust?; Hygienisch?; Leicht druckbar?; Verfügbar?; Kostengünstig?; PETG; EIGNUNG

# Optimierung Seilzüge

## Nähzwirn

Seite 14; Gruppe C | 3D-Druck in der Mechanik | Die Handprothese | 15. Juli 2025; (Polyester, geflochten); Kevlar; (geflochten); Angelschnur Nylonschnur; (PE, geflochten); Dyneema; (UHMwPE); Verfügbarkeit; Preis EIGNUNG; Abriebfestigkeit; Dehnung

# Optimierung Gelenke

Seite 15; Gruppe C | 3D-Druck in der Mechanik | Die Handprothese | 15. Juli 2025; Standardgelenk; Flexibles Gelenk; Schrumpfschlauch-; Gelenk; Abnutzung Komplexität Stabilität; simpler Aufbau komplett druckbar langlebig Federwirkung weniger stabil

noch simpler
in einem Stück
druckbar
abgedichtet
verbesserter Grip
langlebig?

# Anatomische Passformoptimierung

## Skalierungsmöglichkeiten


Seite 16 | Gruppe C | 3D-Druck in der Mechanik | Die Handprothese | 15. Juli 2025

Verzehrte Skalierung:
- Problematisch bei der Banddurchführung
- Verzehrte Gelenke und Finger machen die Skalierung umständlicher und unproportional
Einfache Skalierung:
- Simple Umsetzung
- Druckbar ohne Stützstruktur


Seite 17 | Gruppe C | 3D-Druck in der Mechanik | Die Handprothese | 15. Juli 2025

# Befestigungsalternativen der Bänder


## Empfohlen von e-NABLE

### - Mit Kleber fixieren - TPU-Tensor -> dehnbar

## Neuer Tensor

### - Backentensor - nicht dehnbar - Fixierung mit Druckkraft - einfache Justierung:

1. Länge einstellen
2. Schraube festziehen
Solle einhändig möglich sein

# Gripelemente und Ideen


Seite 18 | Gruppe C | 3D-Druck in der Mechanik | Die Handprothese | 15. Juli 2025

## Empfohlen von e-NABLE

→ Silikoneinsätze in gedruckte Formen gießen

TPU mit modellierter Oberfläche | Latexhandschuh | Latexstoff | Spritzguss mit Heißkleber


Seite 19 | Gruppe C | 3D-Druck in der Mechanik | Die Handprothese | 15. Juli 2025

1.

# Bandführungsalternativen

## Model eines Fingers mit mehreren Befestigungspunkten

1. Ausgangspunkt (Standardmodell)
2. Standardmodell passt sich gut an Oberfläche an
- Halten von z.B. einem Türgriff
3. Finger öffnet sich wobei sich Spitze schließt



Seite 20 | Gruppe C | Gruppe C | 3D-Druck in der Mechanik | Die Handprothese | 15. Juli 2025 Druck in der Mechanik | Die Handprothese | 15/07/25
- Ausgangspunkt (Standardmodell)
- Standardmodell passt sich gut an Oberfläche an
- Halten von z.B. einem Türgriff
- Finger öffnet sich wobei sich Spitze schließt
- Idee: Individueller Seilzug pro Fingerglied mit Bowden-artiger Leitung der Züge
- Nachteil: Ist Starr, passt sich schlecht einer Oberfläche an

### Neue modellierte Finger

Projektionsmethode:

Ansicht von Oben

Ansicht von der Seite

Seite 21 | Gruppe C | Gruppe C | 3D-Druck in der Mechanik | Die Handprothese | 15. Juli 2025 Druck in der Mechanik | Die Handprothese | 15/07/25

### Finger

Plate | 52 g PETG

0,83 € -
1,14 €
Hinge Plate | 17g TPU | 0,31 € -0,43 €
Gauntlet | 66g PETG | 1,05 € -1,45 €
Grip Plate | 7g TPU | 0,13 € -0,18 €

### Gauntlet Cover

### 13g PETG

0,20 € -
0,27 €
Palm | 90g PETG | 1,44 € -1,98 €
Palm Cover | 15g TPU | 0,27 € -0,38 €

### PETG: 16 - 22 €/kg TPU: 18 - 25 €/kg

(Stand 2025-07)

### Gedruckte Teile: 4,23 - 5,38 €

## Kosten und Materialen


# Fazit

Seite 23 | Gruppe C | 3D-Druck in der Mechanik | Die Handprothese | 15. Juli 2025

# Fazit:

# Projektgestaltung und Umsetzung

- Erste Prothese basierend auf Open-Source-Daten
gebaut
- Anatomische Anpassungen nach ersten Treffen mit Antonio
- Kompletter Neuaufbau zur Verbesserung von Passform und Komfort
- Erste Krafttests und Alltagserprobung durch Antonio
- Nachjustierung der Feinmotorik basierend auf Nutzererfahrung
- Ergänzungen durch Antonios Mutter


Seite 24 | Gruppe C | 3D-Druck in der Mechanik | Die Handprothese | 15. Juli 2025

## Fazit:

# Bewertung der Prothese zum Projektabschluss

- Passform und Komfort deutlich verbessert
- Funktionalität im Alltag ausreichend für grundlegende Greifbewegung
- Nutzerfeedback positiv: intuitive Handhabung nach kurzer Eingewöhnung
- Materialwahl: PETG statt PLA (empfohlen) für höhere Belastbarkeit und
Temperaturbeständigkeit
- Reproduzierbarkeit: Design dient als Basis für weitere Exemplare (z.B. Ersatzprothese)
- Kosten unter < 10€ / Prothese
- Gewicht: 181g

Seite 25 | Gruppe C | 3D-Druck in der Mechanik | Die Handprothese | 15. Juli 2025

# Fazit:

# Weiterentwicklungen und zukünftige Unterstützung

- Neue Fingerkuppen aus hochreibungsfähigem Material zur Verbesserung
des Grips geplant
- Langfristige Unterstützung durch Sascha bei Wartung, Reparatur & Nachdruck
- Weitere Handschuhe in Arbeit – individuell angepasst durch die Mutter des Nutzers
- Ersatzprothese wird zeitnah auf Basis des optimierten Designs gefertigt
- Wissensaustausch: Optimierungserkenntnisse werden an die Open-Source-Community zurückgespielt
- Langfristige Perspektive: mögliche Integration von EMG-Sensorik zur aktiven Steuerung

Danke.

Ein großen Dank an Frau Prof. Dr. C. Völlmecke, die es uns ermöglicht hat, dieses Projekt mit kompetenter Beratung durchzuführen. Wir bedanken uns auch bei Yating Ou (M.Sc.) und Narges Panjalipoursangari (M.Sc.) für die stetige Unterstützung. Unser Dank geht auch an alle anderen Beteiligten, für ihr Ideenreichtum

und ihren Rat.

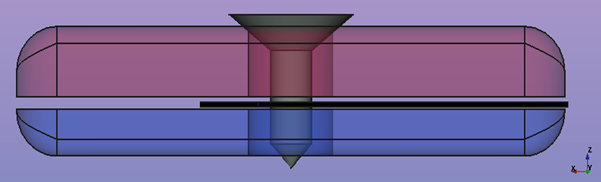
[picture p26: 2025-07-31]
optimisation/04_tensor-system/images/new_tensioner_side_view.png

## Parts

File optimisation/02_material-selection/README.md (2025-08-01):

# Material Selection

This section outlines the material selection process for the prosthetic hand, focusing on both the printed structural components and the cord system. Our goal was to ensure all materials used are suitable for a child-friendly prosthesis — considering **cost**, **availability**, **printability**, **durability**, and above all, **user safety**.

---

## Prosthesis Body

The base components of the prosthesis are produced via **FDM 3D printing**. Suitable materials must be:

- Non-toxic and skin-safe (biocompatible)
- Printable on standard consumer printers (no heated chamber)
- Mechanically durable and impact-resistant
- Resistant to cleaning agents and moderate heat
- Cost-effective and easily sourced (available in maker spaces)

We compared several common 3D printing materials:

Material Selection Chart  
*Figure: Extract from project presentation slide (July 2025)*

### Summary of Key Findings

- **PLA / PLA+**: Very easy to print and affordable, but insufficient temperature resistance. Risk of deformation in hot environments (e.g. car interiors).
- **PETG**: Excellent compromise — better temperature resistance and impact toughness than PLA. Widely available, inexpensive, and easy to print. Chosen as the **main body material**.
- **TPU**: Used selectively for **flexible joints**, due to high elasticity and fatigue resistance.
- **PCTG** *(emerging)*: Similar to PETG, but with improved impact strength and chemical resistance. Promising candidate for future iterations — could enable printed-in-place joints — but still slightly more expensive and less common.

---

## Cord System

The cord system is a critical mechanical component: it transmits motion from the wrist to the fingers. Material selection here directly affects **grip strength**, **responsiveness**, and **long-term reliability**.

Cord Material Selection Chart  
*Figure: Extract from project presentation slide (July 2025)*

### Summary of Key Findings

- **Nylon cords**: Too elastic — leads to energy loss and reduced grip strength.
- **Kevlar**: Strong, but prone to abrasion damage when routed through plastic guides.
- **Braided fishing line (PE)**: Commonly used in e-NABLE designs. Affordable and widely available, but variable in quality.
- **Dyneema® (UHMwPE)**: Exceptional strength-to-weight ratio, low friction, and almost no stretch (~3%). Extremely abrasion-resistant and ideal for compact tendon paths.  
  → Chosen as our **preferred material** (used: 0.4 mm diameter).

If Dyneema® is not available, we recommend using a **braided polyethylene fishing line** with a diameter of **0.3–0.5 mm** as a fallback.

---

## Summary of Material Choices

| Component | Material | Reason |
|---|---|---|
| Main body | PETG | Strong, heat-resistant, widely available |
| Joints | TPU | High elasticity, durable under repeated bending |
| Tendon cords | Dyneema® | Minimal stretch, high durability, low friction |

---

## References

- Internal presentation slide (July 2025): *Material Comparison*
- [e-NABLE community](https://enablingthefuture.org/) – Open-source prosthetic models  
- [Dyneema® product data](https://www.dsm.com/dyneema) – DSM Engineering Materials  
- Mat Bowell, [Kinetic Hand STL](https://www.thingiverse.com/thing:4618922)  
- Steve Wood, [Flexy-Hand STL](https://www.thingiverse.com/thing:380665)

---

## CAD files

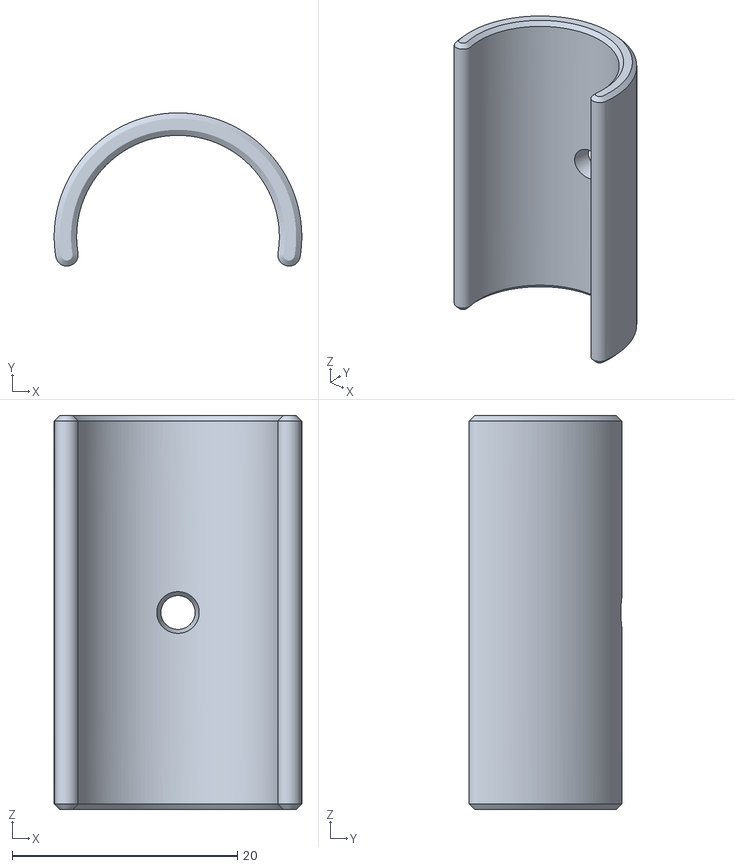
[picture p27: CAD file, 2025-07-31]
optimisation/05_grip-surface/stl/hotglue_snap_mould.stl
22.0 x 13.6 x 35.0

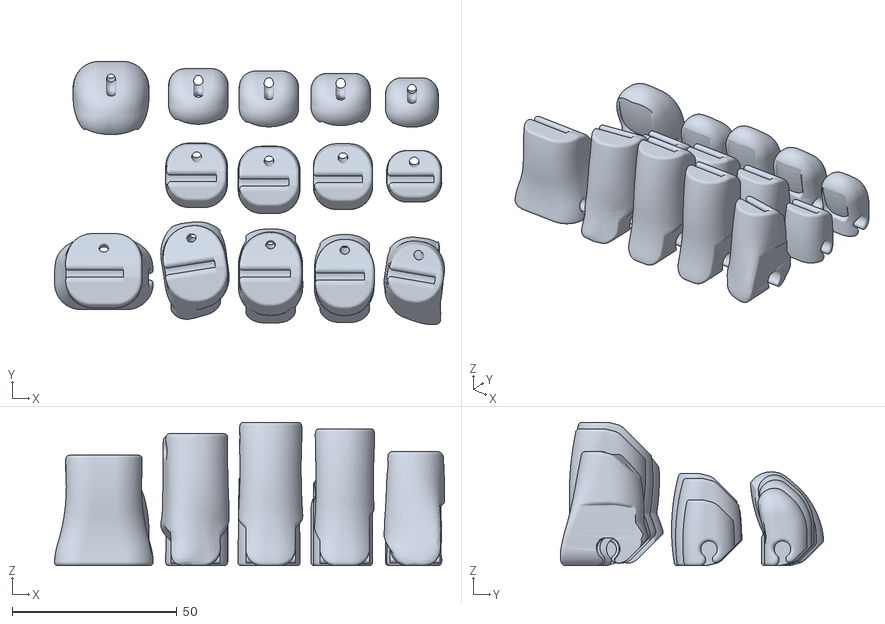
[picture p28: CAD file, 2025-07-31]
resources/original_models/flexy_hand/files/LH_Finger_Plate.stl
118.3 x 79.9 x 43.5

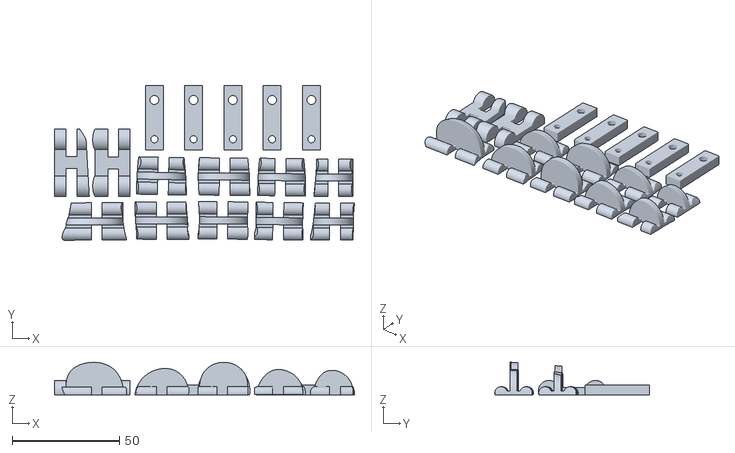
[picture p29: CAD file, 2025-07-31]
resources/original_models/kinetic_hand/Grouped stls/Hinge plate (RH100%).stl
140.1 x 72.2 x 15.2

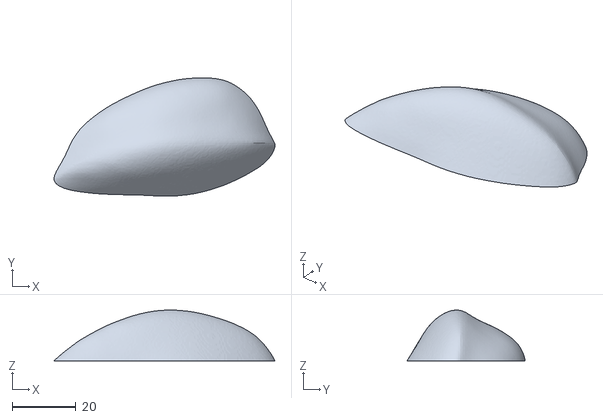
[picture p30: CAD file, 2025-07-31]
resources/original_models/kinetic_hand/Individual stls/Insert A (RH100%).stl
69.6 x 37.3 x 16.0

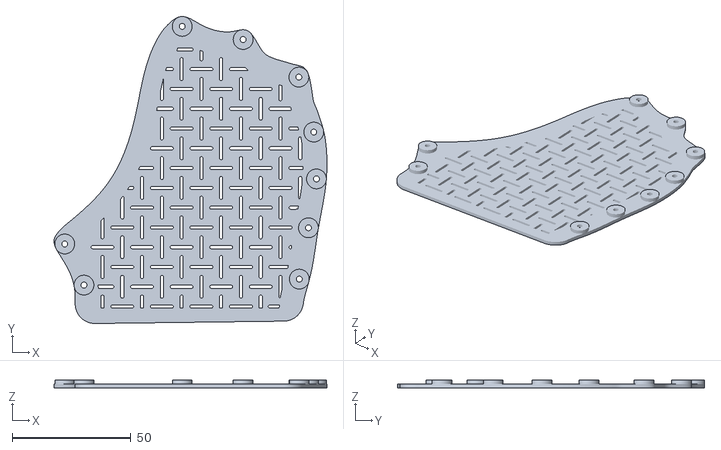
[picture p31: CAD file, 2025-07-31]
resources/original_models/kinetic_hand/Individual stls/Palm variants/Palm cover (RH100%, no thumb or index finger).stl
115.0 x 129.3 x 3.33

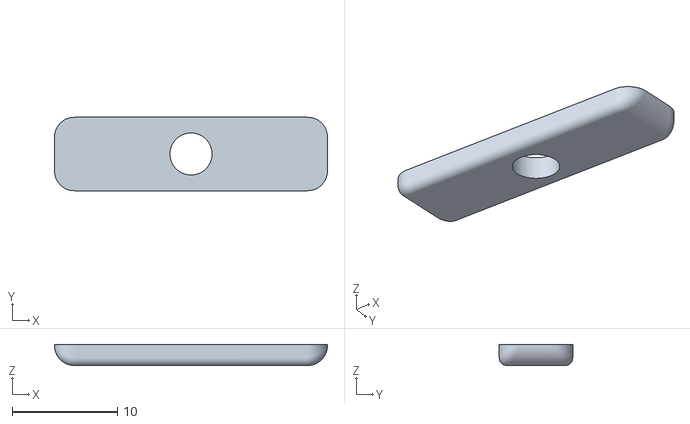
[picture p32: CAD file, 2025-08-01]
v4_final_design/stl/Tensor_new.stl
26.0 x 7.00 x 2.00

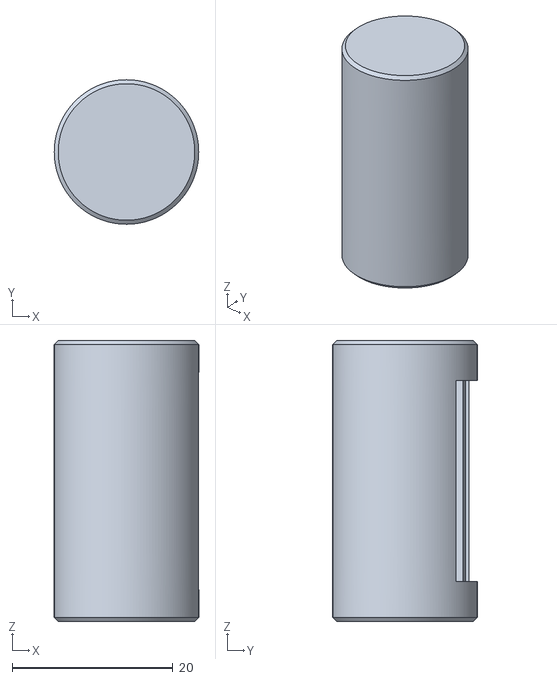
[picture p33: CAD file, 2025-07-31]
optimisation/05_grip-surface/stl/grip_test_finger_with_cavity.stl
18.0 x 18.0 x 35.0

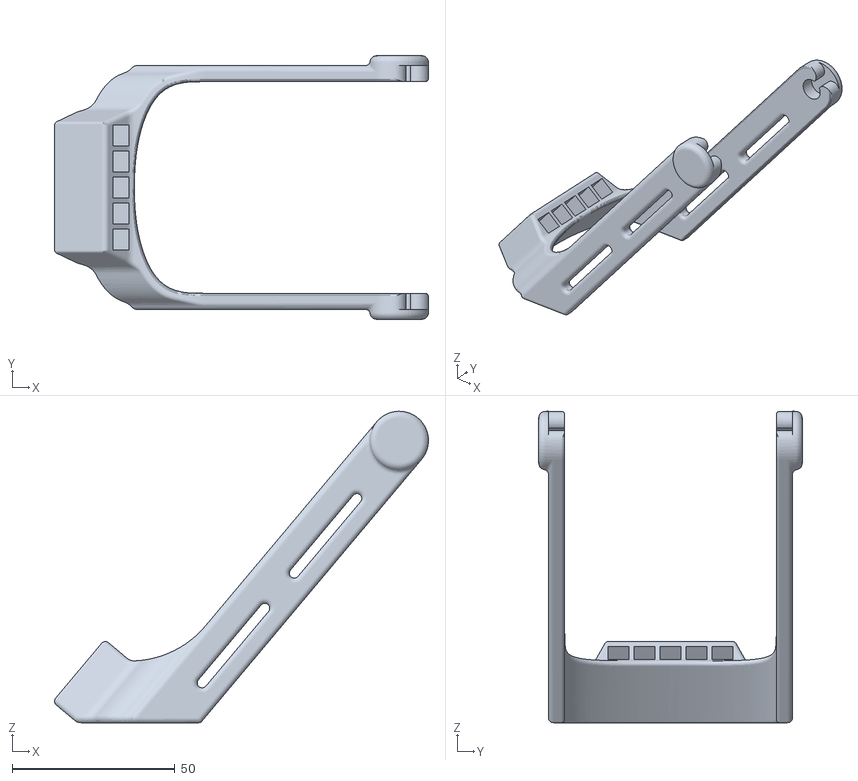
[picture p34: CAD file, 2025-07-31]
resources/original_models/flexy_hand/files/Gauntlet_-_Long_Wider_Wrist.stl
114.9 x 81.0 x 95.7

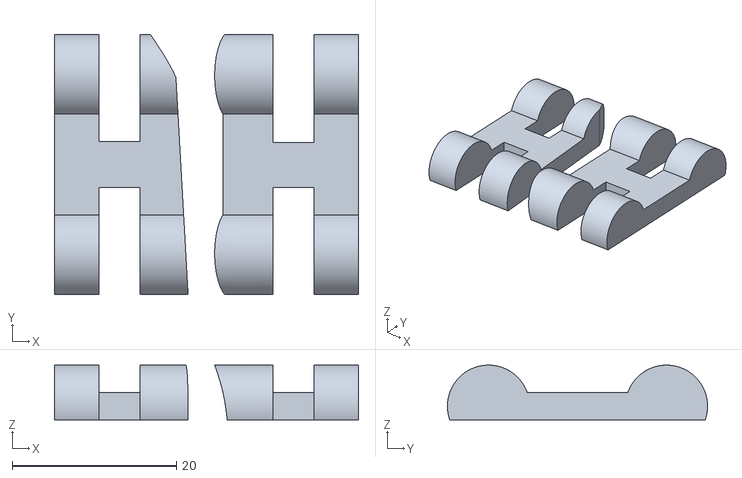
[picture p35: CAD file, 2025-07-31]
resources/original_models/kinetic_hand/Grouped stls/Wrist Hinge plate (RH100%).stl
37.0 x 31.7 x 6.67

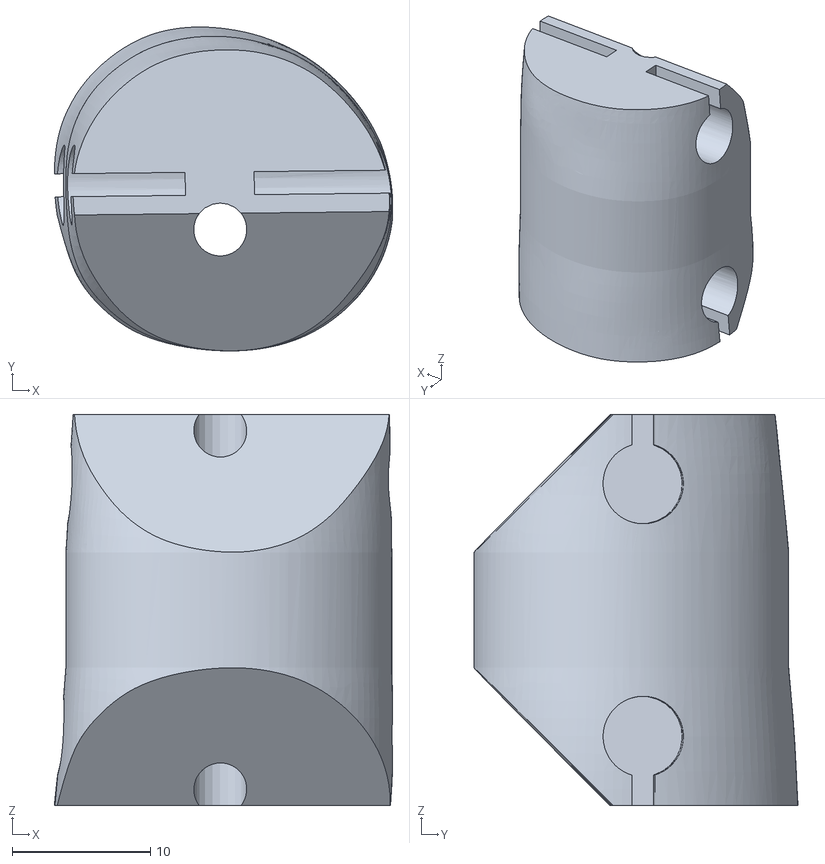
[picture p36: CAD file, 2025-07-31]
resources/original_models/kinetic_hand/Individual stls/Finger 2 (RH100%).STL
24.5 x 23.5 x 28.3

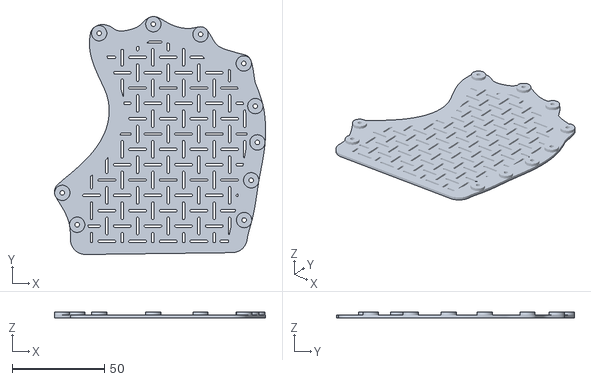
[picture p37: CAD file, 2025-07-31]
resources/original_models/kinetic_hand/Individual stls/Palm variants/Palm cover (RH100%, no thumb).stl
114.7 x 129.3 x 3.33

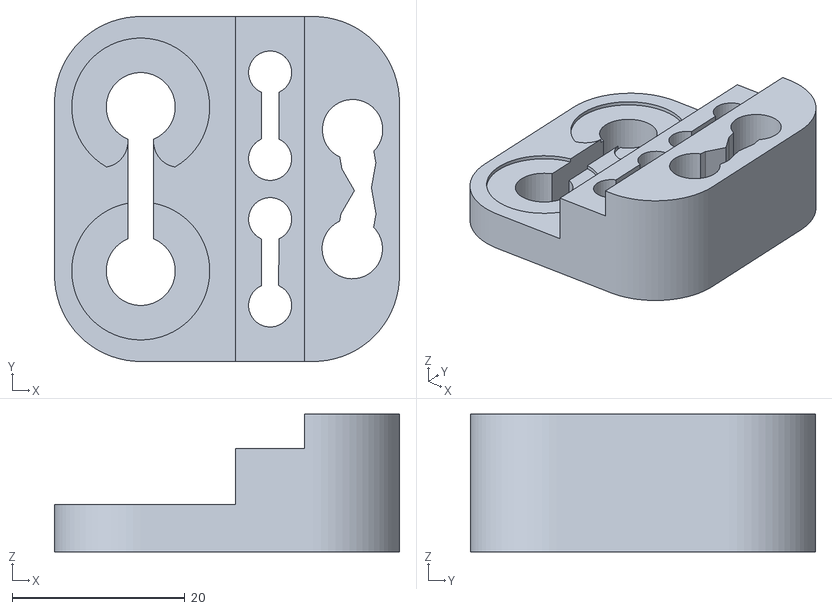
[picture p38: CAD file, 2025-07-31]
resources/original_models/flexy_hand/files/Mould.stl
40.0 x 40.0 x 16.0

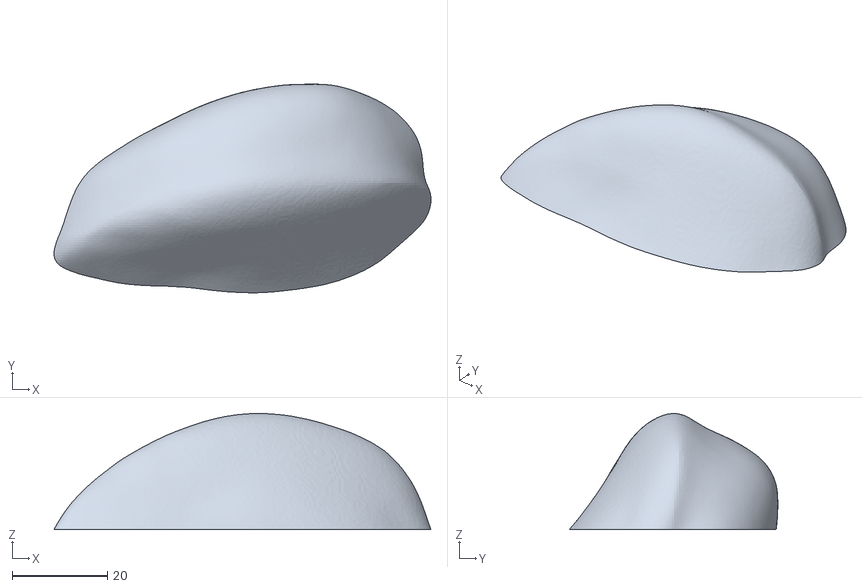
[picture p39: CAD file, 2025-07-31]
resources/original_models/kinetic_hand/Individual stls/Insert B (RH100%).stl
79.1 x 43.8 x 24.4

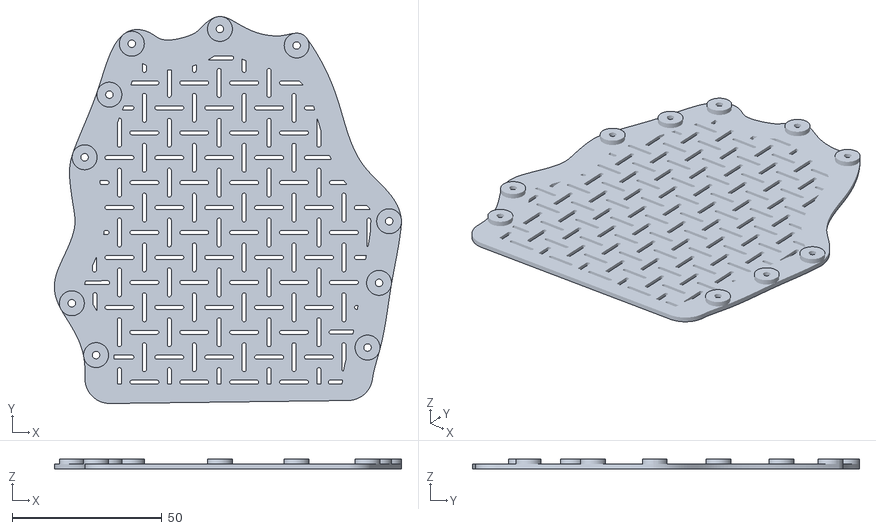
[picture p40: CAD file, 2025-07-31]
resources/original_models/kinetic_hand/Individual stls/Palm variants/Palm cover (RH100%, no little finger).stl
116.0 x 129.3 x 3.33

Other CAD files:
resources/original_models/flexy_hand/files/FFX_-_Flexy-Hinge_Wrist.stl
resources/original_models/kinetic_hand/Individual stls/Hinge 7 (RH100%).stl
resources/original_models/flexy_hand/files/RH_Hand_Body_-_Wider_Wrist_-_Opposable_Thumb.stl
resources/original_models/kinetic_hand/Individual stls/Finger 9 (RH100%).stl
resources/original_models/flexy_hand/files/7.stl
resources/original_models/flexy_hand/files/8.stl
resources/original_models/flexy_hand/files/FFX_-_Bat_Connection_-_Orientation_1.stl
resources/original_models/flexy_hand/files/FFX_-_Finger_Hinge_Plate.stl
resources/original_models/flexy_hand/files/Flexy-Hand_2_Gauntlet_-_Thermoform.stl
resources/original_models/flexy_hand/files/Gauntlet_-_Long.stl
resources/original_models/flexy_hand/files/Gauntlet_-_Short.stl
resources/original_models/flexy_hand/files/Gauntlet_-_Short_Wider_Wrist.stl
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

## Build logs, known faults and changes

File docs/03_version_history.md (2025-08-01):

# Version History – Pediatric Hand Prosthesis

This document tracks the development milestones of the prosthetic design.

---

## v4 (Current Version) – Final Prototype
**Date:** July 2025  
**Status:** Functional and tested  
**Key Features:**
- Custom string tensioning clamp for one-handed operation
- Dyneema® cords for low-friction, high-durability performance
- Latex grip surfaces for improved usability
- Joints printed from softer TPU 

---

## v3 – Grip Optimization & Cable Routing  
**Date:** June 2025  
**Status:** Prototype  
**Changes:**
- Added grip surface testing (TPU, latex, hot glue)
- Settled on uniform scaling to keep wire channels functional
- Initial user feedback integrated
- Tuned in prinitng settings for optimal joint strength

---

## v2 – Fit & Geometry Adaptation  
**Date:** May 2025  
**Status:** Working prototype  
**Changes:**
- Scaled e-NABLE Kinetic Hand model for individual fit
- Adjusted wrist socket and gauntlet geometry
- Tested various scaling strategies (uniform vs. proportional)
- Settled on PETG and TPU for main components and Dyneema® for cords

---

## v1 – First Working Model (Flexy-Hand)  
**Date:** April 2025  
**Status:** Proof of concept  
**Changes:**
- Printed and assembled Gyrobot Flexy-Hand 2
- Identified issues: too large size, limited adjustability, poor grip, visible cables
- Used nylon strings → observed loss of force due to elasticity
- Basis for further research and benchmarking

---

## Planned Versions

| Version | Description | Target Date |
|---|---|---|
| v5 | Improved grip tips (textured rubber/silicone) | Q4 2025 |
| v6 | Printable in one piece | TBD |
| v7 | Optional EMG integration (active sensing) | TBD |

---

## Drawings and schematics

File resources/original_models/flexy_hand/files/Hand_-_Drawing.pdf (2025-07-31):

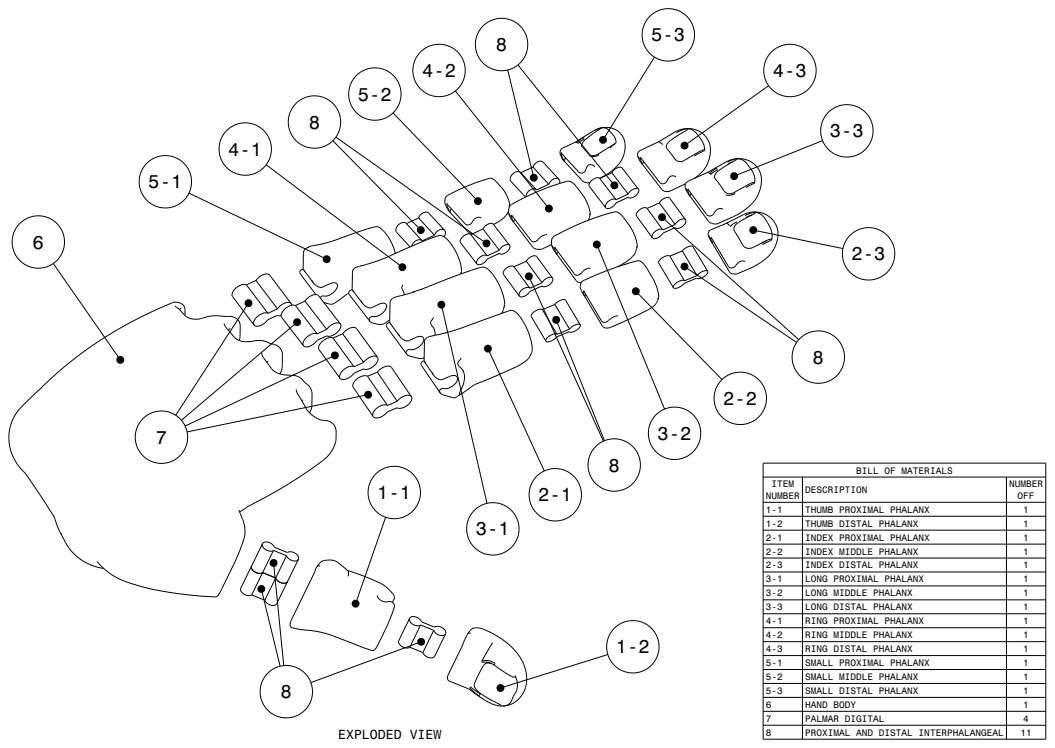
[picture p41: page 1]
EXPLODED VIEW; PROXIMAL AND DISTAL INTERPHALANGEAL

BILL OF MATERIALS

ITEM NUMBER | DESCRIPTION | NUMBER OFF

1-1 | THUMB PROXIMAL PHALANX | 1
1-2 | THUMB DISTAL PHALANX | 1
2-1 | INDEX PROXIMAL PHALANX | 1
2-2 | INDEX MIDDLE PHALANX | 1
2-3 | INDEX DISTAL PHALANX | 1
3-1 | LONG PROXIMAL PHALANX | 1
3-2 | LONG MIDDLE PHALANX | 1
3-3 | LONG DISTAL PHALANX | 1
4-1 | RING PROXIMAL PHALANX | 1
4-2 | RING MIDDLE PHALANX | 1
4-3 | RING DISTAL PHALANX | 1
5-1 | SMALL PROXIMAL PHALANX | 1
5-2 | SMALL MIDDLE PHALANX | 1
5-3 | SMALL DISTAL PHALANX | 1
6 | HAND BODY | 1
7 | PALMAR DIGITAL | 4

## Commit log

2025-07-25 update material selection and base model selection
2025-07-25 write about joint config and update material selection
2025-07-25 rename material selection
2025-07-31 update tensioners
2025-07-31 update grip pads
    [grip_test_finger_with_cavity.stl, hotglue_snap_mould.stl]
2025-07-31 update fit-scaling and add original models
    [7.stl, 8.stl, FFX_-_Bat_Connection_-_Orientation_1.stl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]
2025-07-31 update shrink tube joints
2025-08-01 Add new tensor
    [Tensor_new.stl]
